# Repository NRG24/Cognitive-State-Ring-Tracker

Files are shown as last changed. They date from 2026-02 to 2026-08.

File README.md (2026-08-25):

# NERVA Ring

An open-source, sensor-packed smart ring designed to monitor cognitive health and autonomic nervous system metrics rather than traditional fitness tracking.

## Project Overview

The NERVA Ring shifts the focus of wearable technology away from step-counting and workouts toward real-time mental well-being. By embedding precise biosensors into a compact, flexible PCB form factor, the device continuously captures physiological indicators tied directly to stress, mental fatigue, and psychological arousal.

## Core Features

* **Cognitive Focus:** Tailored strictly for mental wellness monitoring rather than physical fitness or gym tracking.
* **Reviewed Hardware Design:** The v1 circuitry was modeled and validated in LT-Spice; the v2 netlist has been reviewed pin-by-pin against every device datasheet. No v2 board has been built or bench-validated yet.
* **Ultra-Compact Layout:** All hardware components optimized to fit onto a highly constrained, circular flex PCB architecture.
* **Wireless Telemetry:** Real-time, low-latency data streaming to mobile devices using Bluetooth Low Energy (BLE).
* **Intelligent Software Pipeline:** Dynamic in-app data filtering to remove motion artifacts and anomalies, powering a custom algorithm that delivers a "Cognitive Score" out of 100 alongside meaningful behavioral insights.

## Hardware Architecture

The current board is **NERVA Ring v2**, a complete part change from v1 — the MCU, both sensors, the op-amp, and the entire power path were replaced. Everything under `hardware/` and `firmware/` in this repo still describes the v1 board; see [Board Revisions](#board-revisions).

### Core components

| Role | Part | I²C address (7-bit) |
|---|---|---|
| MCU / BLE | u-blox ANNA-B402-00B (nRF52833) | — |
| PPG (HR / SpO2) | MAXM86161 | `0x62` (`0xC4`/`0xC5` 8-bit) |
| IMU + die temperature | ST LSM6DSV | `0x6B` — SA0 tied to 1V8 |
| PMIC / charger / fuel gauge | TI BQ25120A | `0x6A` (fixed) |
| GSR analog front end | TI OPA2333 (dual op-amp) | — |
| LED boost converter | TI TPS61240 (fixed 5 V) | — |

All three I²C devices share a single bus. The IMU sits at **`0x6B`, not the ST default `0x6A`**: SA0 was originally grounded, which collided with the BQ25120A's fixed `0x6A`, so it was moved to the 1V8 rail.

### Pin map

**ANNA-B402 module pin numbers are not nRF GPIO numbers.** The `Pxx.yy` column is what firmware addresses.

There is **no UART and no USB** on this board — SWD is the only wired interface, so logging has to go over RTT rather than a serial port.

Because XL1/XL2 are grounded, the low-frequency clock has to come from the internal RC oscillator. There is no crystal to select.

### Power architecture

* **BQ25120A** is charger, buck regulator, and fuel gauge in one part. It supplies the SYS rail feeding the ANNA module, both sensors, and the analog front end. There is no separate LDO and no 3.3 V rail — the 3V3 rail was deleted, nothing uses it, and the PMIC's load switch / LDO output stays off (`LSCTRL`, ball E3, is tied to GND).
* **SYS runs at 1.9 V, not the 1.8 V default.** The default's −2.5 % corner is 1.755 V, which is below the OPA2333's 1.800 V minimum supply and only 55 mV above the ANNA's 1.70 V brown-out threshold. 1.9 V clears both, and costs nothing in GSR accuracy because the measurement is ratiometric — the rail cancels out.
* **The TS (thermistor) pin, ball C3, is physically unroutable on this layout and floats.** With TS sensing active the charger faults and delivers no current, so `TS_EN` has to be cleared before the cell will charge at all.
* Disabling TS also removes JEITA over-temperature protection from a lithium cell worn against skin, so charge-temperature limiting has to be reimplemented against the LSM6DSV die temperature and applied through the PMIC's `CE` bit.
* **Battery percentage comes from the BQ25120A's VBMON.** The v1 board had no fuel gauge at all.
* **TPS61240** generates the fixed 5 V VLED rail for the PPG, gated by `BOOST_EN`. It exists because of the green LED: VF is 3.0–3.8 V, against 2.1–2.5 V for red and 1.6–1.9 V for IR.
* Battery capacity (mAh) is still an open decision — it sets the fast-charge current and any honest runtime estimate.

### GSR front end

* Excitation is gated by `GSR_PWR` (P0.11, high drive) so the analog section can be powered down between samples, saving roughly 37 µA.
* Output lands on **AIN1 (P0.03)**. The SAADC is configured **reference VDD/4, gain 1/4**, so full scale equals VDD and the reading is ratiometric against the same rail that drives the excitation — supply drift cancels. The internal 0.6 V reference breaks that property.
* **40 µs acquisition time** is required by the 100 kΩ source impedance of R6.
* The C10/R6 filter has a ~100 ms time constant; allow ~300 ms after powering the front end before the first valid sample.
* Sampling must stay at **≥10 Hz** — skin-conductance responses peak ~1.4 s after onset, which is ~14 samples across the rise at 10 Hz but only ~3 at 2 Hz.
* Nominal conversion, 12-bit (0–4095): `G[µS] ≈ code × 0.009692 − 10.989`. Derived from nominal resistor values, so it needs trimming against a known resistance.

### PPG front end

* The MAXM86161 is powered **entirely from the 5 V VLED rail**. It is single-supply with an internal LDO, so taking `BOOST_EN` low unpowers the part completely and resets every register — a full re-init is required on each duty cycle.
* **Its interrupt pin is deliberately left unconnected**; the FIFO has to be polled.
* The I²C bus runs at 1.8 V and the MAXM86161 needs VIH ≥ 1.4 V, so no level shifter is required despite the 5 V VLED.
* **LED current range is a power-path constraint.** At the 124 mA range the boost pulls ~186 mA from the cell; on a small ring LiPo (~3 Ω internal resistance) that is ~560 mV of droop and starts crowding the BQ25120A's UVLO. The 31 mA range draws ~45 mA, about 135 mV of droop.

### IMU

* LSM6DSV at `0x6B`, with INT1 wired to P0.16.
* It is **not** an LSM6DS3 — different `WHO_AM_I` and different ODR / full-scale register encodings, so v1 register values do not carry the same meaning.
* Embedded temperature sensor at `OUT_TEMP_L/H` (0x20/0x21), 256 LSB/°C with 0 LSB = 25 °C. This is the die temperature used for the software charge-temperature limiting described above.

```
NERVA_Ring/
├── app/                        # Flutter mobile app ("GSR Streamer")
│   ├── lib/
│   │   ├── main.dart           # App entry point
│   │   ├── ble_service.dart    # BLE communication layer
│   │   ├── cognitive_scorer.dart
│   │   ├── gsr_analyzer.dart
│   │   ├── models/             # Data models
│   │   ├── screens/            # UI screens
│   │   ├── services/           # Business logic services
│   │   └── widgets/            # Reusable UI components
│   └── pubspec.yaml
├── firmware/                   # Arduino firmware sketches
│   ├── gsr_heart_ble/          # Main firmware + docs
│   │   ├── gsr_heart_ble.ino   # BLE biometric streaming (XIAO prototype)
│   │   └── *.ino              # Variant sketches (power-optimized, all-features, etc.)
│   ├── simple_ble/             # Minimal BLE test
│   └── *.ino                  # Standalone test sketches
├── hardware/                   # Hardware design files (v1 board)
│   ├── NERVA RING-bom.csv      # JLCPCB bill of materials (v1)
│   ├── BOM.md                  # Formatted BOM reference (v1)
│   ├── gsr_wearable.kicad_sch  # KiCad schematic
│   ├── gsr_wearable.kicad_pro  # KiCad project
│   ├── Ring CAD.step           # 3D CAD model
│   ├── pcb/                    # PCB layout files
│   ├── SCHEMATIC_CHECKLIST.md  # Design review checklist
│   ├── GSR_CIRCUIT_INTEGRATION.md
│   ├── PCB_LAYOUT_STRATEGY.md
│   └── *.md                   # Additional design docs
├── docs/                       # Software architecture docs
│   ├── ACTIVITY_RECOGNITION.md
│   ├── STRESS_PATTERN_ANALYSIS.md
│   ├── HAPTIC_NOTIFICATIONS.md
│   └── *.md
└── scripts/                    # Build/utility scripts
```

## Bill of Materials (Summary)

Active components on the **v2** board:

| Component | Part | Qty |
|---|---|-----|
| MCU / BLE module | ANNA-B402-00B (u-blox, nRF52833) | 1 |
| PPG sensor | MAXM86161 | 1 |
| IMU | LSM6DSV | 1 |
| PMIC / charger / fuel gauge | BQ25120A | 1 |
| GSR op-amp | OPA2333 (dual) | 1 |
| LED boost converter | TPS61240 (fixed 5 V) | 1 |
| Battery | Curved ring-type LiPo — capacity TBD | 1 |

> The BOM files in this repo — [`hardware/BOM.md`](hardware/BOM.md) and the raw JLCPCB export [`hardware/NERVA RING-bom.csv`](hardware/NERVA%20RING-bom.csv) — are the **v1** build, including passives, costs and LCSC part numbers. A v2 BOM has not been generated.

## Sensors & Data Streams

| Metric | Sensor (v2) | BLE UUID (suffix) | Type |
|---|---|---|---|
| GSR (Skin Conductance) | OPA2333 front end → SAADC AIN1 | `...0002` | Int |
| Heart Rate | MAXM86161 PPG | `...0003` | Int |
| Temperature | LSM6DSV die temp | `...0004` | Float |
| HRV (RMSSD) | Derived from PPG | `...0005` | Float |
| SpO2 | MAXM86161 PPG | `...0006` | Int |
| Battery Level | BQ25120A VBMON | `...0007` | Int |

**BLE Service UUID:** `19B10000-E8F2-537E-4F6C-D104768A1214`

The v2 IMU also makes raw accelerometer and gyroscope streams available. UUIDs and payload types above describe the app currently in `app/`; the BLE characteristic set is firmware/app scope and is not covered by this hardware pass.

## Board Revisions

Every design file in `hardware/` and every sketch in `firmware/` describes the **v1** board. v2 replaced all of it:

| Role | v1 | v2 (current) |
|---|----|---|
| MCU / BLE | Raytac MDBT42V (nRF52832) | u-blox ANNA-B402-00B (nRF52833) |
| PPG | MAX30102 | MAXM86161 |
| IMU | LSM6DSR (LSM6DSRTR) | LSM6DSV |
| GSR op-amp | LM324PWR (quad) | OPA2333 (dual) |
| Power | TLV70018DDCR 1.8 V LDO | BQ25120A PMIC (charger + buck + fuel gauge) |
| LED supply | — | TPS61240 fixed 5 V boost |
| Temperature source | MAX30102 die temp | LSM6DSV die temp |
| Battery monitoring | none | BQ25120A VBMON |

Consequences worth knowing:

* The KiCad project, Gerbers, BOM, and all layout/schematic notes under `hardware/` are v1 and have not been regenerated.
* v1 firmware does not port to v2. Beyond the sensor changes, the Adafruit nRF52 Arduino core supports nRF52832/nRF52840 only, while the ANNA-B402 is an nRF52833.

**Within the v1 documents themselves**, several files still reference even earlier parts: `SCHEMATIC_CHECKLIST.md`, `PCB_LAYOUT_STRATEGY.md`, and `GSR_CIRCUIT_INTEGRATION.md` mention LSM6DS3, TLV9004 (UQFN-14), and a 3.3 V MCP1700T-3302E LDO, and the JLCPCB BOM CSV lists MDBT50Q-1MV2 in the MCU slot rather than the MDBT42V actually fitted. `hardware/BOM.md` tracks that list. The firmware docs in `firmware/gsr_heart_ble/` describe the XIAO nRF52840 prototyping setup, not a ring board of either revision.

## Getting Started

### Mobile App
```bash
cd app
flutter pub get
flutter run
```

### Firmware (Prototype with XIAO nRF52840)
1. Install Arduino IDE with Seeed nRF52 board support
2. Install libraries: `ArduinoBLE`, `OneWire`, `DallasTemperature`
3. Wire sensors per `firmware/gsr_heart_ble/SETUP_INSTRUCTIONS.md`
4. Upload `firmware/gsr_heart_ble/gsr_complete_all_features.ino`

### Hardware
The KiCad project, Gerbers, and BOM in `hardware/` are the **v1** board: a 2-layer flex design with components on both sides, 0402/0201 passives, assembled by JLCPCB. v2 design files are not in this repo — the v2 description above comes from its netlist and datasheet review.

Bringing up a v2 board: attach a debug probe to SWD (module pins 41/42) and power it from a partially charged cell. **A fresh board will not charge on its own** — the floating TS pin holds the BQ25120A off until firmware clears `TS_EN`.

---

https://github.com/user-attachments/assets/21d7508c-1ee5-49b8-9717-f8bbbc1bc319







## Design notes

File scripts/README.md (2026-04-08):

# scripts/ — nRF52832 Flash Tools (Raspberry Pi Debug Probe)

Scripts to erase and flash the Raytac MDBT42 (nRF52832) using a Raspberry Pi Debug Probe over SWD via OpenOCD.

---

## Hardware Wiring

| Raspberry Pi Debug Probe | nRF52832 (MDBT42) |
|---|---|
| SWDIO | SWDIO (P0.26) |
| SWCLK | SWDCLK (P0.27) |
| GND | GND |
| VTref (3.3V) | VDD (3.3V) |
| RESET (optional) | RESET |

> **Note:** Power the nRF52832 from an external supply or your PCB — do not rely on the probe to power the target unless it's a low-power test setup.

---

## Requirements

Install OpenOCD on the Raspberry Pi:

```bash
sudo apt update
sudo apt install openocd
```

Verify OpenOCD supports CMSIS-DAP (it should on modern Raspberry Pi OS):

```bash
openocd --version
```

---

## Files

| File | Purpose |
|---|---|
| `rpi_debug_probe.cfg`  | OpenOCD config — CMSIS-DAP/SWD, nRF52832 target |
| `flash.sh` | Flash a firmware `.hex` to the nRF52832 |
| `erase.sh` | Mass-erase the nRF52832 (clears all flash) |

---

## Usage

### 1. Copy scripts to Raspberry Pi

```bash
scp scripts/rpi_debug_probe.cfg scripts/flash.sh scripts/erase.sh pi@<PI_IP>:~/nrf52_tools/
ssh pi@<PI_IP>
chmod +x ~/nrf52_tools/flash.sh ~/nrf52_tools/erase.sh
```

### 2. Test connection (verify OpenOCD can see target)

```bash
openocd -f ~/nrf52_tools/rpi_debug_probe.cfg -c "init; reset halt; mdw 0x10000000; exit"
```

Expected output includes the chip ID — if you see `0x10000000: XXXXXXXX` the probe is connected.

### 3. Erase the chip (optional, do before flashing if chip is locked)

```bash
cd ~/nrf52_tools
./erase.sh
```

### 4. Flash firmware

```bash
cd ~/nrf52_tools
./flash.sh /path/to/firmware.hex
```

Example with Arduino-exported hex:

```bash
./flash.sh ~/firmware/gsr_heart_ble.ino.hex
```

---

## Building Firmware (two options)

### Option A — Arduino IDE (easiest)

1. Install **Arduino IDE 2.x**
2. Add nRF5 board support URL in preferences:
   ```
   https://sandeepmistry.github.io/arduino-nRF5/package_nRF5_index.json
   ```
3. Install board: **Nordic Semiconductor nRF5 Boards** → select **Nordic nRF52832**
4. Open `firmware/gsr_heart_ble/` sketch
5. Sketch → Export Compiled Binary → outputs a `.hex`
6. Copy `.hex` to RPi and flash with `./flash.sh`

### Option B — nRF5 SDK + ARM GCC

1. Download [nRF5 SDK 17.1.0](https://www.nordicsemi.com/Software-and-tools/Software/nRF5-SDK)
2. Install arm-none-eabi-gcc:
   ```bash
   sudo apt install gcc-arm-none-eabi
   ```
3. Build:
   ```bash
   cd <sdk>/examples/ble_peripheral/ble_app_uart/pca10040/s132/armgcc
   make
   ```
4. Flash the merged softdevice + app hex:
   ```bash
   ./flash.sh _build/nrf52832_xxaa.hex
   ```

---

## Softdevice Note

If using SoftDevice (BLE stack), you must flash it separately **once** before flashing your app:

```bash
# flash S132 softdevice first
./flash.sh /path/to/s132_nrf52_7.3.0_softdevice.hex

# then flash your app
./flash.sh /path/to/your_app.hex
```

Download S132 from: https://www.nordicsemi.com/Software-and-tools/Software/S132

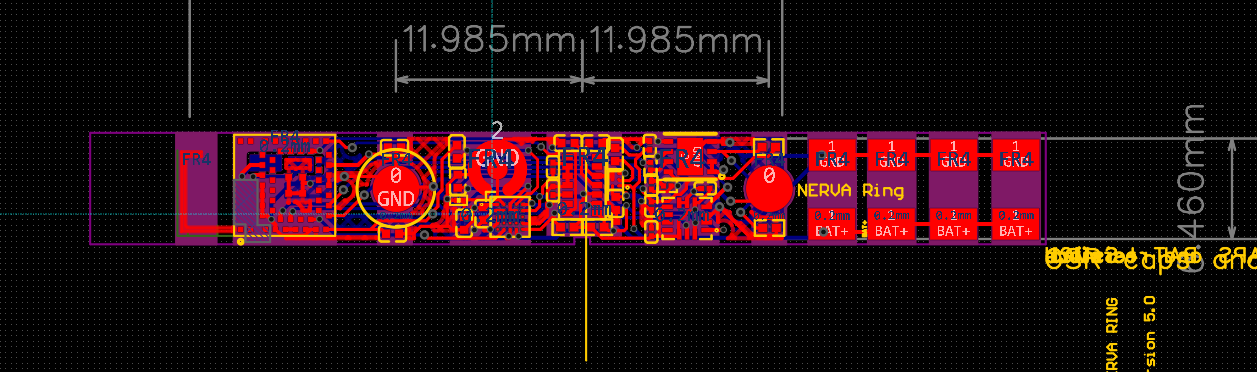
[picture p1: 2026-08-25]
hardware/pcb/PCB and Schematic/PCB_image.png

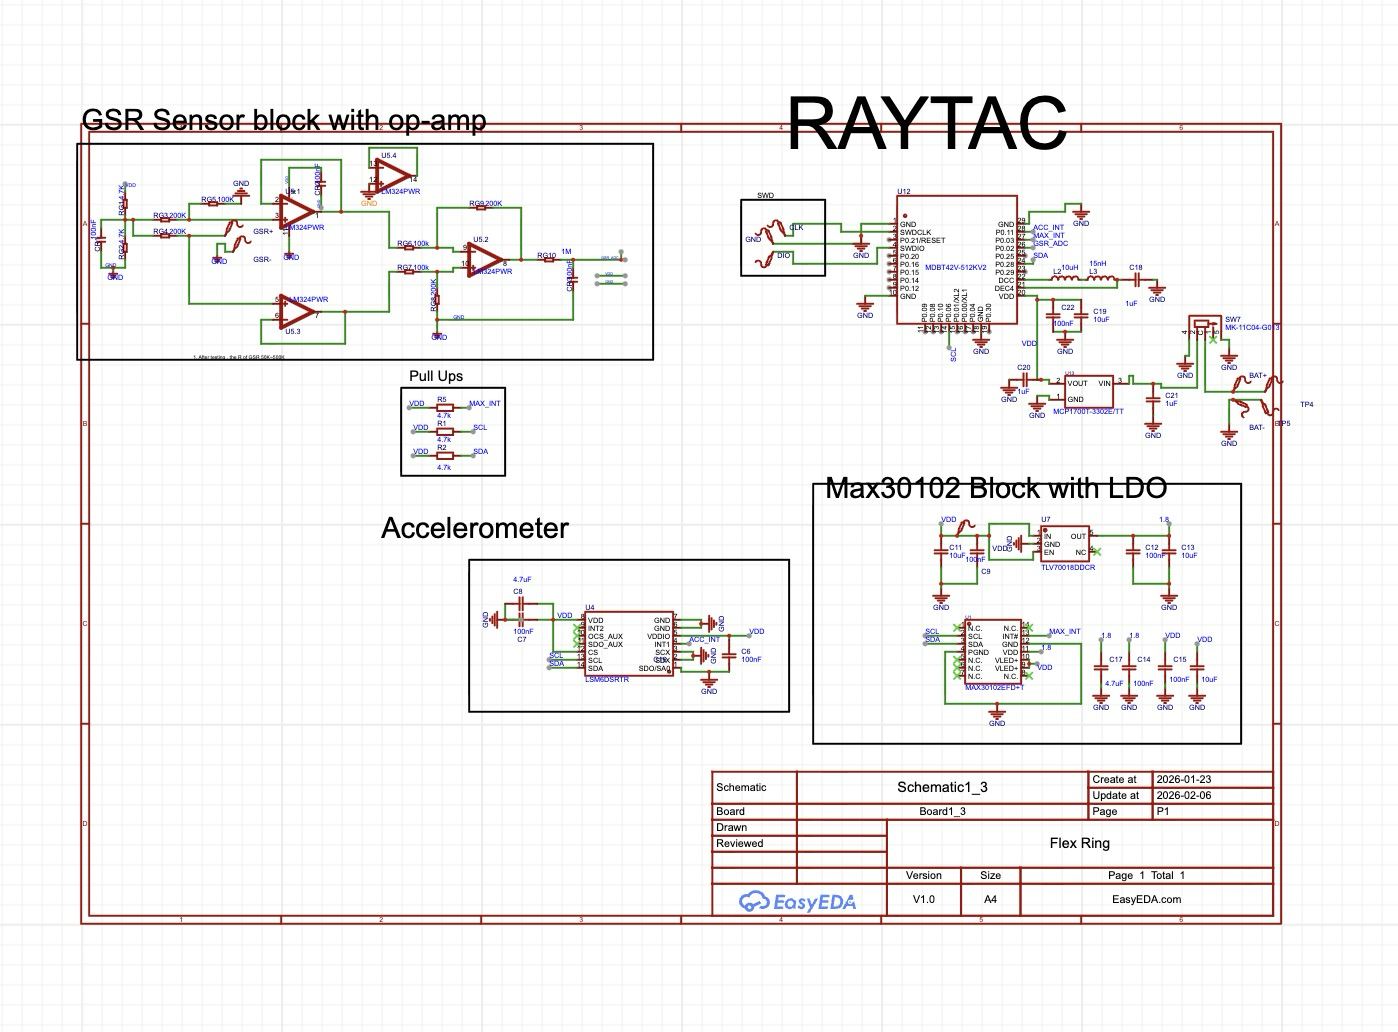
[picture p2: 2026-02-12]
hardware/pcb/PCB and Schematic/Schematic.png

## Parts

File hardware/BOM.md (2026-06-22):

# NERVA Ring - Bill of Materials

> **Source of truth:** [`NERVA RING-bom.csv`](NERVA%20RING-bom.csv) is the JLCPCB export. This document is a formatted reference.

## Order Summary

| Item | Description | Qty | Cost (USD) | Supplier |
|---|---|-----|---|---|
| Curved LiPo Battery | Ring-type rechargeable Li-Ion cell for wearable devices | 5 | $27.00 | Alibaba |
| Flex PCB + Assembly | 2-layer flex PCB with SMT assembly (all components except battery) | 2 | $160.60 | JLCPCB |
| Raytac MDBT42V-P | BLE MCU module (nRF52832), pre-order for PCB assembly | 2 | $11.06 | JLCPCB Pre-Order |
| | **Total** | | **$198.66** | |

## PCBA Parts List

Components placed by JLCPCB assembly service.

### Active Components (ICs)

| Ref | Part Number | Description | Package | Qty | Manufacturer | LCSC | Unit Price |
|-----|---|---|---|-----|---|---|---|
| U10 | MDBT42V-512KV2 | BLE MCU module (nRF52832) | SMD Module | 1 | Raytac | C5118826 | $1.02 |
| U1 | MAX30102EFD+T | PPG sensor (HR, SpO2, temp) | OESIP-14 (5.6x3.3mm) | 1 | Analog Devices / Maxim | C6454833 | $1.79 |
| U4 | LSM6DSRTR | 6-axis IMU (accel + gyro) | LGA-14 (3.0x2.5mm) | 1 | STMicroelectronics | C784817 | $0.41 |
| U5 | LM324PWR | Quad op-amp (GSR circuit) | TSSOP-14 (5.0x4.4mm) | 1 | Texas Instruments | C7942 | $0.03 |
| U7 | TLV70018DDCR | 1.8V LDO regulator | SOT-23-5 (3.0x1.7mm) | 1 | Texas Instruments | C79924 | $0.02 |

### Passive Components

#### Capacitors

| Ref | Value | Designators | Package | Qty | Notes |
|-----|---|---|---|-----|---|
| C6-C7, C9, C12, C14-C15, C_VDD1, C_VDDH1 | 100nF | Bypass / decoupling | 0402 | 8 | |
| C8, C17 | 4.7uF | Bulk decoupling | 0603 | 2 | |
| C11, C13, C16, C_VDD, C_VDDH | 10uF | Bulk decoupling | 0603 | 5 | |
| CR1, CR2, CR3 | 100nF | GSR circuit | 0402 | 3 | |

**Total capacitors: 18**

#### Resistors

| Ref | Value | Designators | Package | Qty | Notes |
|-----|---|---|---|-----|---|
| R1, R2, R5 | 4.7k | I2C pull-ups / general | 0402 | 3 | |
| R6 | 10K | General | 0402 | 1 | |
| RG1, RG2 | 4.7K | GSR circuit | 0402 | 2 | |
| RG3, RG4, RG8, RG9 | 200K | GSR feedback | 0402 | 4 | |
| RG5 | 100K | GSR circuit | 0402 | 1 | |
| RG6, RG7 | 100k | GSR circuit | 0402 | 2 | |
| RG10 | 1M | GSR output | 0402 | 1 | |

**Total resistors: 14**

#### Inductors

| Ref | Value | Designator | Package | Qty | Notes |
|-----|---|---|---|-----|---|
| L1 | 10uH | L1 | 0603 | 1 | DCDC circuit |

**Total inductors: 1**

### Connectors, Electrodes & Test Points

| Ref | Part | Designators | Qty | Notes |
|-----|---|---|-----|---|
| H4 | PZ254V-11-02P | H4 | 1 | 2-pin header (battery connector), LCSC C492401 |
| — | Custom pogo pins | GSR+, GSR- | 2 | GSR skin-contact electrodes |
| — | 2-pin magnetic pogo connector | CHRG | 1 | Magnetic charging connector (Alibaba) |
| BAT+, BAT- | Test-Point | BAT+, BAT- | 2 | Battery connection test points (2mm) |
| TP_VDD | Test-Point | TP_VDD | 1 | Power rail test point (0.5mm) |

## Component Count Summary

| Category | Count |
|---|---|
| ICs | 5 |
| Capacitors | 18 |
| Resistors | 14 |
| Inductors | 1 |
| Connectors | 3 |
| Test Points | 3 |
| **Total** | **44** |

## Discrepancies With Other Documentation

The JLCPCB BOM CSV lists MDBT50Q-1MV2 for the MCU slot, but the actual module used is the **MDBT42V** (nRF52832). The following docs have other stale references:

| Document | References | Actual Part on PCB |
|---|---|---|
| `SCHEMATIC_CHECKLIST.md` | LSM6DS3 | LSM6DSR (LSM6DSRTR) |
| `SCHEMATIC_CHECKLIST.md` | MCP1700T-3302E (3.3V LDO) | TLV70018DDCR (1.8V LDO) |
| `SCHEMATIC_CHECKLIST.md` | TLV9004 quad op-amp | LM324PWR |
| `PCB_LAYOUT_STRATEGY.md` | TLV9004IRUCR, LSM6DS3, MCP1700T-3302E | See above |
| `GSR_CIRCUIT_INTEGRATION.md` | TLV9004IRUCR (UQFN-14), 0201 passives | LM324PWR (TSSOP-14), 0402 passives |
| `GSR_CIRCUIT_INTEGRATION.md` | RG1 = 100kΩ | RG1 = 4.7K (per CSV BOM) |
| `GSR_CIRCUIT_INTEGRATION.md` | 100µF bulk cap (0603/0805) | No 100µF cap in BOM; largest is 10µF |

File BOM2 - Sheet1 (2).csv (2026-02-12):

Item | Quantity | Link | Price | Notes
Raytac MDBT42V | 2 | https://jlcpcb.com/partdetail/RAYTAC-MDBT50Q1MV2/C5118826 | 27.84 | Pre-order for PCBA
JLCPCB PCB | 5 | NA | 7.79
PCBA | 2 | NA | 231.47
Curved LiPo Battery | 5 | https://www.alibaba.com/product-detail/150728-22mAh_11000020635153.html | 30.9 | Already owned
 |  | Subtotal: | 267.1
 |  | Shipping: | 17.5 | This is Cheapest Shipping
 |  | Total: | 284.6
PCBA Parts list excluding Raytac MCU
No. | Quantity | Comment | Designator | Footprint | Value | Manufacturer Part | Manufacturer | Supplier Part | Supplier | JLCPCB Price
1 | 2 | Test-Point | BAT+,BAT- | Test-Point-2mm
2 | 8 | 100nF | C6,C7,C9,C12,C14,C15,C_VDD1,C_VDDH1 | C0402 | 100nF
3 | 2 | 4.7uF | C8,C17 | C0603 | 4.7uF
4 | 5 | 10uF | C11,C13,C16,C_VDD,C_VDDH | C0603 | 10uF
5 | 3 | 100nF | CR1,CR2,CR3 | C0402
6 | 1 | PZ254V-11-02P | H4 | HDR-TH_2P-P2.54-V-M |  | PZ254V-11-02P | XFCN(兴飞) | C492401 | LCSC | 0.0018
7 | 1 | 10uH | L1 | L0603 | 10uH
8 | 3 | 4.7k | R1,R2,R5 | R0402 | 4.7k
9 | 1 | 10K | R6 | R0402 | 10K
10 | 2 | 4.7K | RG1,RG2 | R0402
11 | 4 | 200K | RG3,RG4,RG8,RG9 | R0402
12 | 1 | 100K | RG5 | R0402
13 | 2 | 100k | RG6,RG7 | R0402
14 | 1 | 1M | RG10 | R0402
15 | 1 | Test-Point | TP_VDD | Test-Point-0.5mm
16 | 1 | MAX30102EFD+T | U1 | OESIP-14_L5.6-W3.3-P0.80-TL |  | MAX30102EFD+T | ADI(亚德诺)/MAXIM(美信) | C6454833 | LCSC | 1.7855
17 | 1 | LSM6DSRTR | U4 | LGA-14_L3.0-W2.5-P0.50-BR |  | LSM6DSRTR | ST(意法半导体) | C784817 | LCSC | 0.4076
18 | 1 | LM324PWR | U5 | TSSOP-14_L5.0-W4.4-P0.65-LS6.4-BL |  | LM324PWR | TI(德州仪器) | C7942 | LCSC | 0.0289
19 | 1 | TLV70018DDCR | U7 | SOT-23-5_L3.0-W1.7-P0.95-LS2.8-BR |  | TLV70018DDCR | TI(德州仪器) | C79924 | LCSC | 0.0249
20 | 1 | MDBT50Q-1MV2 | U10 | COMM-SMD_MDBT50Q-1MV2-1 |  | MDBT50Q-1MV2 | RAYTAC | C5118826 | LCSC | 1.0176

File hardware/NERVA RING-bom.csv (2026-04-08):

Name | Purpose | Quantity | Total Cost (USD) | Link | Distributor
Smart Cell for Small Wearable Devices High-Energy Compact Power Source Ring-Type Lithium-Ion Battery OEM ODM Rechargeable | Curved LiPo Battery to power the PCB | 5 | 27 | https://www.alibaba.com/product-detail/Smart-Cell-for-Small-Wearable-Devices_11000020635153.html | Alibaba (via Trusted Supplier I've used before)
Flex PCB + PCB Assembly | This is the flexible PCB with all of the needed components except for the battery- Assembly included. I got the cheapest shipping option available. | 2 | 160.6 |  | JLCPCB
Raytac MDBT42V - P | MCU- Preorder for PCB Assembly | 2 | 11.06 | https://jlcpcb.com/parts/componentSearch?searchTxt=mdbt42v-512kv2 | JLCPCB Pre-Order
 |  | Total: | 198.6
PCBA Parts list excluding Raytac MCU
No. | Quantity | Comment | Designator | Footprint | Value | Manufacturer Part | Manufacturer | Supplier Part | Supplier | JLCPCB Price
1 | 2 | Test-Point | BAT+,BAT- | Test-Point-2mm
2 | 8 | 100nF | C6,C7,C9,C12,C14,C15,C_VDD1,C_VDDH1 | C0402 | 100nF
3 | 2 | 4.7uF | C8,C17 | C0603 | 4.7uF
4 | 5 | 10uF | C11,C13,C16,C_VDD,C_VDDH | C0603 | 10uF
5 | 3 | 100nF | CR1,CR2,CR3 | C0402
6 | 1 | PZ254V-11-02P | H4 | HDR-TH_2P-P2.54-V-M |  | PZ254V-11-02P | XFCN(兴飞) | C492401 | LCSC | 0.0018
7 | 1 | 10uH | L1 | L0603 | 10uH
8 | 3 | 4.7k | R1,R2,R5 | R0402 | 4.7k
9 | 1 | 10K | R6 | R0402 | 10K
10 | 2 | 4.7K | RG1,RG2 | R0402
11 | 4 | 200K | RG3,RG4,RG8,RG9 | R0402
12 | 1 | 100K | RG5 | R0402
13 | 2 | 100k | RG6,RG7 | R0402
14 | 1 | 1M | RG10 | R0402
15 | 1 | Test-Point | TP_VDD | Test-Point-0.5mm
16 | 1 | MAX30102EFD+T | U1 | OESIP-14_L5.6-W3.3-P0.80-TL |  | MAX30102EFD+T | ADI(亚德诺)/MAXIM(美信) | C6454833 | LCSC | 1.7855
17 | 1 | LSM6DSRTR | U4 | LGA-14_L3.0-W2.5-P0.50-BR |  | LSM6DSRTR | ST(意法半导体) | C784817 | LCSC | 0.4076
18 | 1 | LM324PWR | U5 | TSSOP-14_L5.0-W4.4-P0.65-LS6.4-BL |  | LM324PWR | TI(德州仪器) | C7942 | LCSC | 0.0289
19 | 1 | TLV70018DDCR | U7 | SOT-23-5_L3.0-W1.7-P0.95-LS2.8-BR |  | TLV70018DDCR | TI(德州仪器) | C79924 | LCSC | 0.0249
20 | 1 | MDBT50Q-1MV2 | U10 | COMM-SMD_MDBT50Q-1MV2-1 |  | MDBT50Q-1MV2 | RAYTAC | C5118826 | LCSC | 1.0176

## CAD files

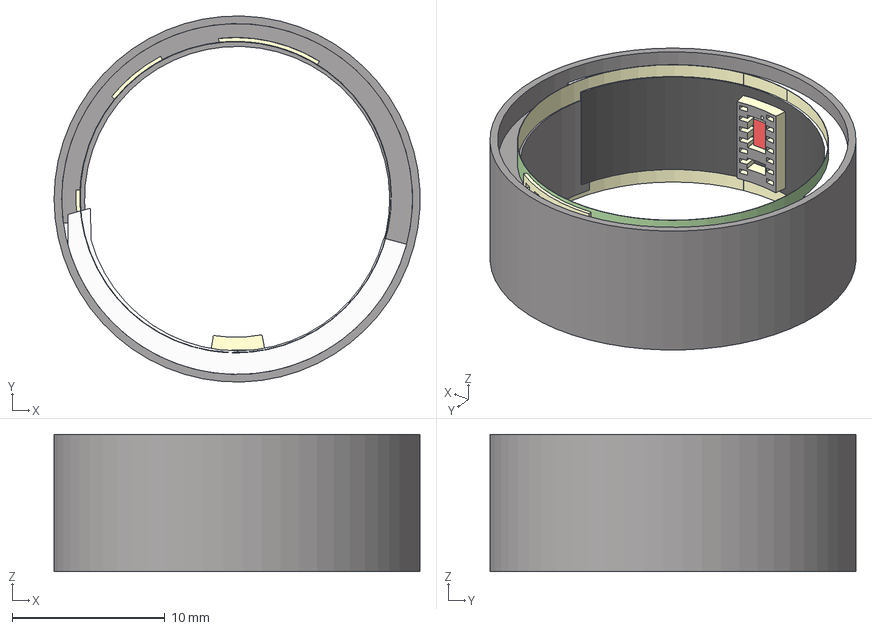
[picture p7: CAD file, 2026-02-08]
hardware/Ring CAD.step
24.0 x 24.0 x 9.00 mm

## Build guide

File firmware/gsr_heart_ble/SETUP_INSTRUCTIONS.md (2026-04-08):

# XIAO nRF52840 Complete Biometric System Setup

## 📋 Overview

This is the **complete Arduino sketch** that provides ALL features for the GSR Streamer Flutter app:
- ✅ GSR (Galvanic Skin Response) monitoring
- ✅ Heart Rate with pulse detection
- ✅ Heart Rate Variability (HRV/RMSSD)
- ✅ Finger Temperature (DS18B20)
- ✅ SpO2 Blood Oxygen (optional MAX30102)
- ✅ Battery level monitoring
- ✅ Real-time waveform data
- ✅ Power optimization with auto-sleep

---

# XIAO nRF52840 BLE GSR Sensor Setup Instructions

## Hardware Requirements

### Required Components:
1. **XIAO nRF52840 Board** - Main microcontroller
2. **GSR Sensor** - Galvanic Skin Response sensor
3. **Pulse Sensor** - Heart rate detection
4. **DS18B20 Temperature Sensor** - Waterproof version for finger temp
5. **4.7kΩ Resistor** - Pull-up for DS18B20
6. **Battery Components** (for battery monitoring):
   - 2x 10kΩ resistors (voltage divider)
   - 110-500mAh LiPo battery
7. **Breadboard and jumper wires**

### Optional Components:
- **MAX30102** - For accurate SpO2 blood oxygen measurement

---

## Complete Wiring Diagram

```
XIAO nRF52840 Pin Connections:
╔════════════════════════════════════════════════════════════╗
║ SENSOR CONNECTIONS                                         ║
╠════════════════════════════════════════════════════════════╣
║ A0 ──────► GSR Sensor (Signal)                             ║
║ A1 ──────► Pulse Sensor (Signal)                           ║
║ D6 ──────► DS18B20 (Data) + 4.7kΩ pull-up to 3.3V         ║
║ A5 ──────► Battery Voltage (via voltage divider)           ║
║ SDA ─────► MAX30102 SDA (optional)                         ║
║ SCL ─────► MAX30102 SCL (optional)                         ║
║ 3V3 ─────► All sensors VCC                                 ║
║ GND ─────► All sensors GND                                 ║
║ LED ─────► Built-in (connection indicator)                 ║
╚════════════════════════════════════════════════════════════╝
```

### Battery Voltage Monitor Circuit

```
Battery Voltage Divider (for battery % monitoring):

    Battery+ (4.2V max)
        │
       ┌┴┐
       │R│ 10kΩ
       └┬┘
        ├────────► A5 (XIAO) [measures ~2.1V max]
        │
       ┌┴┐
       │R│ 10kΩ
       └┬┘
        │
       GND

This divides battery voltage by 2, so XIAO can safely measure it.
```

### Detailed Connections

#### GSR Sensor
- **VCC** → XIAO 3.3V
- **GND** → XIAO GND
- **Signal** → XIAO A0

#### Pulse Sensor
- **Red Wire (VCC)** → XIAO 3.3V
- **Black Wire (GND)** → XIAO GND
- **Purple Wire (Signal)** → XIAO A1

#### DS18B20 Temperature Sensor
- **Red Wire (VCC)** → XIAO 3.3V
- **Black Wire (GND)** → XIAO GND
- **Yellow Wire (Data)** → XIAO D6
- **4.7kΩ Resistor** → Between Data (D6) and VCC (3.3V)

```
Temperature Sensor Pull-up Resistor:
       3.3V
        │
       ┌┴┐
       │R│ 4.7kΩ
       └┬┘
        │
        ├────────► D6 (XIAO)
        │
      ──┴──  DS18B20 Data Pin
```

## Required Arduino Libraries

Install these libraries via Arduino IDE Library Manager:

1. **ArduinoBLE** (version 1.3.6 or later)
   - For: BLE communication
   - Install: `Sketch > Include Library > Manage Libraries > Search "ArduinoBLE"`

2. **OneWire** (version 2.3.7 or later)
   - For: DS18B20 communication protocol
   - Install: `Sketch > Include Library > Manage Libraries > Search "OneWire"`

3. **DallasTemperature** (version 3.9.0 or later)
   - For: DS18B20 temperature sensor interface
   - Install: `Sketch > Include Library > Manage Libraries > Search "DallasTemperature"`

## Board Setup in Arduino IDE

1. **Install XIAO nRF52840 Board Support**
   - Open Arduino IDE
   - Go to `File > Preferences`
   - Add to "Additional Boards Manager URLs":
     ```
     https://files.seeedstudio.com/arduino/package_seeeduino_boards_index.json
     ```
   - Go to `Tools > Board > Boards Manager`
   - Search for "Seeed nRF52 Boards"
   - Install "Seeed nRF52 Boards" by Seeed Studio

2. **Select Board**
   - `Tools > Board > Seeed nRF52 Boards > Seeed XIAO BLE - nRF52840`

3. **Select Port**
   - Connect XIAO via USB-C
   - `Tools > Port > [Select your XIAO port]`

## Upload Instructions

1. **Open the sketch**
   - Open `gsr_heart_temp_complete.ino` in Arduino IDE

2. **Verify Hardware is Connected**
   - Connect all sensors as per wiring diagram
   - Ensure 4.7kΩ pull-up resistor is in place for DS18B20

3. **Upload**
   - Click "Upload" button (→) in Arduino IDE
   - Wait for "Done uploading" message

4. **Monitor Serial Output**
   - Open Serial Monitor (`Tools > Serial Monitor`)
   - Set baud rate to **115200**
   - You should see:
     ```
     ═══════════════════════════════════════════════
     GSR Streamer - Complete Biometric System v2.0
     ═══════════════════════════════════════════════
     Initializing DS18B20 temperature sensor... Found 1 device(s)
     Initializing BLE... OK
     BLE advertising started as 'GSR_HEART'
     Waiting for connection...
     ═══════════════════════════════════════════════
     ```

---

## 📊 What Data Does This Send?

The complete sketch sends **6 data streams** to your Flutter app:

### 1. **GSR (Galvanic Skin Response)**
- **UUID:** 19B10002-E8F2-537E-4F6C-D104768A1214
- **Type:** Integer (0-1023)
- **Update Rate:** 10 times/second
- **What it measures:** Skin conductance (stress, arousal, emotion)
- **Used for:** Stress detection, trigger identification, baseline tracking

### 2. **Heart Rate**
- **UUID:** 19B10003-E8F2-537E-4F6C-D104768A1214
- **Type:** Integer (BPM)
- **Range:** 30-200 BPM
- **Update Rate:** Real-time (on each heartbeat)
- **What it measures:** Beats per minute with 5-beat smoothing
- **Used for:** Activity recognition, stress analysis, waveform display

### 3. **Temperature**
- **UUID:** 19B10004-E8F2-537E-4F6C-D104768A1214
- **Type:** Float (°Celsius)
- **Range:** 20-45°C typical
- **Update Rate:** Every 2 seconds
- **What it measures:** Finger temperature via DS18B20
- **Used for:** Stress patterns, health monitoring, waveform display

### 4. **HRV (Heart Rate Variability)**
- **UUID:** 19B10005-E8F2-537E-4F6C-D104768A1214
- **Type:** Float (milliseconds)
- **Calculation:** RMSSD (Root Mean Square of Successive Differences)
- **Update Rate:** After each heartbeat (calculated from last 10 RR intervals)
- **What it measures:** Variation between heartbeats
- **Used for:** Stress level, recovery status, autonomic balance
- **Note:** Higher HRV = better (more relaxed/recovered)

### 5. **SpO2 (Blood Oxygen)**
- **UUID:** 19B10006-E8F2-537E-4F6C-D104768A1214
- **Type:** Integer (%)
- **Range:** 70-100%
- **Update Rate:** Continuous (if MAX30102 connected)
- **What it measures:** Blood oxygen saturation
- **Used for:** Health monitoring, activity recognition
- **Note:** Currently simulated (98%) - requires MAX30102 for real data

### 6. **Battery Level**
- **UUID:** 19B10007-E8F2-537E-4F6C-D104768A1214
- **Type:** Integer (%)
- **Range:** 0-100%
- **Update Rate:** Every 10 seconds
- **What it measures:** LiPo battery charge percentage
- **Used for:** Low battery warnings, power management

---

## ⚡ Power Management Features

The sketch includes **smart power optimization**:

### When Connected (Active Mode):
- All sensors active
- Data sent every 100ms
- LED on solid
- Power draw: ~15-20mA

### When Disconnected (Idle Mode):
- Light sleep after 0 seconds
- Still advertising for connections
- Slower polling
- Power draw: ~5-10mA

### Deep Sleep (After 60 seconds idle):
- Ultra-low power mode
- Only BLE advertising active
- Slow "heartbeat" LED (2 second blink)
- Power draw: ~0.5-2mA
- **Battery life:** Days to weeks!

---

## LED Status Indicators

| Pattern | Meaning |
|---|---|
| **3 Fast Blinks** (startup) | System ready, BLE advertising |
| **Solid ON** | Connected to app, streaming data |
| **Quick pulse with heartbeat** | Heart beat detected |
| **Slow blink (2s)** | Deep sleep mode, waiting for connection |
| **Rapid flashing** | Error - check Serial Monitor |

---

## 🔧 Calibration & Tuning

### Pulse Sensor Threshold
If heart rate is not detecting properly:

```cpp
const int PULSE_THRESHOLD = 550;  // Line 67 - adjust this!
```

- **Too low (< 500):** False beats, erratic readings
- **Too high (> 650):** Misses beats
- **Sweet spot:** Usually 520-580 depending on your sensor

**How to calibrate:**
1. Open Serial Monitor
2. Watch raw pulse values
3. Set threshold to ~70% of peak value

### Battery Voltage Calibration

## Troubleshooting

### Temperature Sensor Not Detected
**Symptoms**: "Temperature sensors found: 0"

**Solutions**:
1. Check 4.7kΩ pull-up resistor is connected between Data (D6) and 3.3V
2. Verify DS18B20 wiring (Red=VCC, Black=GND, Yellow=Data)
3. Try a different DS18B20 sensor (they can fail)
4. Measure resistance between Data and VCC pins (should be ~4.7kΩ)

### No Heart Rate Detection
**Symptoms**: BPM stays at 0

**Solutions**:
1. Ensure Pulse Sensor is firmly pressed against fingertip
2. Clean the sensor surface
3. Adjust `PULSE_THRESHOLD` in code (line 21) - try values 500-600
4. Check Serial Monitor for "♥ Beat detected!" messages
5. Ensure good skin contact with the sensor

### GSR Values Stuck or Not Changing
**Symptoms**: GSR reads constant value

**Solutions**:
1. Attach GSR electrodes to clean, dry skin (fingers work best)
2. Ensure electrodes have good contact
3. Wait 30-60 seconds for sensor to stabilize
4. Check that GSR sensor is powered (3.3V)

### BLE Connection Issues
**Symptoms**: Flutter app can't find device

**Solutions**:
1. Verify device name is "GSR_HEART" in Serial Monitor
2. Check UUIDs match between Arduino and Flutter app
3. Reset XIAO (press reset button)
4. Move phone/computer closer to XIAO
5. Turn Bluetooth off/on on phone
6. Close other BLE apps that might interfere

### Temperature Reading Errors
**Symptoms**: "Warning: Temperature sensor read error"

**Solutions**:
1. Check DS18B20 is genuine (many clones exist)
2. Verify pull-up resistor value (4.7kΩ)
3. Shorten wires if connection is long (>1 meter)
4. Try a different digital pin
5. Power cycle the XIAO

## Sensor Calibration

### Pulse Sensor Auto-Calibration
The sketch automatically calibrates the pulse threshold every 5 seconds based on signal range. For manual tuning:
- Open Serial Monitor
- Observe signal min/max values
- Set `PULSE_THRESHOLD` to midpoint between min and max

### GSR Baseline
GSR values vary by person and conditions. Typical ranges:
- **Dry skin**: 200-400
- **Normal**: 400-600
- **Sweaty/stressed**: 600-800+

### Temperature Reference
- **Normal finger temp**: 30-35°C (86-95°F)
- **Cold hands**: 25-30°C (77-86°F)
- **Warm/active**: 35-37°C (95-99°F)

## Data Stream Format

### BLE Characteristics

| Characteristic | UUID | Data Type | Range | Update Rate |
|---|---|---|---|---|
| GSR | 19B10002 | Int32 (LE) | 0-1023 | 20 Hz |
| Heart Rate | 19B10003 | Int32 (LE) | 30-200 BPM | 20 Hz |
| Temperature | 19B10004 | Float32 (LE) | 20-45°C | 0.5 Hz |

### Serial Debug Output Format
```
GSR: 512 | BPM: 72 | Temp: 32.5°C
♥ Beat detected! BPM: 75
```

## Power Consumption

- **Scanning**: ~15 mA
- **Connected & Streaming**: ~20 mA
- **Battery Life** (500 mAh LiPo): ~20-25 hours continuous use

## Safety Notes

⚠️ **Important Safety Information**:
- This is a DIY educational device, **NOT** medical equipment
- Do not use for medical diagnosis or treatment
- Ensure all connections are insulated to prevent shorts
- Use only 3.3V power supply (XIAO's voltage)
- Do not submerge electronics (only DS18B20 probe if waterproof)

## Next Steps

Once hardware is set up and sketch is uploaded:

1. **Verify Serial Output**: Confirm all sensors are detected
2. **Test Flutter App**: Run `flutter run -d iPhone` or `flutter run -d macos`
3. **Connect**: Tap "Connect to Device" in app
4. **Monitor Data**: Watch real-time waveforms update
5. **Calibrate**: Allow 2-3 minutes for sensors to stabilize

## Support

For issues or questions:
- Check Serial Monitor output for error messages
- Verify all wiring matches diagram
- Ensure libraries are up to date
- Try each sensor individually to isolate problems

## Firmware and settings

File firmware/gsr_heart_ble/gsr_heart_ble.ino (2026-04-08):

#include <Wire.h>
#include "MAX30105.h"
#include "heartRate.h"
#include <ArduinoBLE.h>  // BLE activated!

MAX30105 particleSensor;

// BLE Service and Characteristics - exact Flutter app UUIDs
BLEService gsrService("19B10000-E8F2-537E-4F6C-D104768A1214");
BLEIntCharacteristic gsrCharacteristic("19B10002-E8F2-537E-4F6C-D104768A1214", BLERead | BLENotify);
BLEIntCharacteristic heartCharacteristic("19B10003-E8F2-537E-4F6C-D104768A1214", BLERead | BLENotify);
BLEFloatCharacteristic tempCharacteristic("19B10004-E8F2-537E-4F6C-D104768A1214", BLERead | BLENotify);

// BLE variables - ready to activate
bool deviceConnected = false;

// Temperature variables
float temperature = 0.0;
unsigned long lastTempRead = 0;
const unsigned long TEMP_READ_INTERVAL = 2000; // Read temperature every 2 seconds

const byte RATE_SIZE = 20;  //Increased for much smoother averaging
byte rates[RATE_SIZE];     //Array of heart rates
byte rateSpot = 0;
long lastBeat = 0;  //Time at which the last beat occurred

float beatsPerMinute;
int beatAvg;
float smoothedBPM = 0.0;  //Additional smoothing layer

// GSR Variables - simple
const int GSR_PIN = A0;
float gsrValue = 0.0;
float gsrBaseline = 0.0;
float gsrVariability = 0.0;
const int GSR_SAMPLES = 10;
float gsrReadings[GSR_SAMPLES] = {0};
int gsrIndex = 0;

// HRV Variables - minimal and careful
const int HRV_BUFFER_SIZE = 10;
unsigned long rrIntervals[HRV_BUFFER_SIZE];
int rrIndex = 0;
unsigned long lastRRTime = 0;
float hrv = 0.0;

// SpO2 Variables - simple and careful
float spo2 = 0.0;
float redACValue = 0, irACValue = 0;
float redDCValue = 0, irDCValue = 0;
int spo2SampleCount = 0;

void setup() {
  Serial.begin(9600);
  Serial.println("Initializing...");

  // Initialize sensor
  if (!particleSensor.begin(Wire, I2C_SPEED_FAST)) {
    Serial.println("MAX30102 was not found. Please check wiring/power. ");
    while (1)
      ;
  }
  Serial.println("Place your index finger on the sensor with steady pressure.");

  particleSensor.setup();                     //Configure sensor with default settings
  particleSensor.setPulseAmplitudeRed(0x0A);  //Turn Red LED to low to indicate sensor is running
  particleSensor.setPulseAmplitudeGreen(0);   //Turn off Green LED
  
  // Enable temperature reading
  particleSensor.enableDIETEMPRDY();  //Enable the temp ready interrupt
  
  // Initialize BLE (placeholder for now)
  initializeBLE();
}

void loop() {
  long irValue = particleSensor.getIR();
  uint32_t redValue = particleSensor.getRed(); // Get red value for SpO2

  if (checkForBeat(irValue) == true) {
    //We sensed a beat!
    long delta = millis() - lastBeat;
    lastBeat = millis();

    beatsPerMinute = 60 / (delta / 1000.0);

    if (beatsPerMinute < 255 && beatsPerMinute > 20) {
      rates[rateSpot++] = (byte)beatsPerMinute;  //Store this reading in the array
      rateSpot %= RATE_SIZE;                     //Wrap variable

      //Take average of readings
      beatAvg = 0;
      for (byte x = 0; x < RATE_SIZE; x++)
        beatAvg += rates[x];
      beatAvg /= RATE_SIZE;
      
      // Additional exponential smoothing for very stable BPM
      if (smoothedBPM == 0.0) {
        smoothedBPM = beatAvg;  // Initialize on first reading
      } else {
        smoothedBPM = (smoothedBPM * 0.85) + (beatAvg * 0.15);  // Heavy smoothing
      }
      
      // HRV calculation - only when we have valid beats
      if (lastRRTime > 0) {
        unsigned long rrInterval = millis() - lastRRTime;
        if (rrInterval > 400 && rrInterval < 1500) { // Tighter range for more realistic RR intervals (40-150 BPM)
          rrIntervals[rrIndex] = rrInterval;
          rrIndex = (rrIndex + 1) % HRV_BUFFER_SIZE;
          calculateHRV();
        }
      }
      lastRRTime = millis();
    }
  }

  // SpO2 calculation - simple and non-interfering
  if (irValue > 50000 && redValue > 1000) {
    calculateSpO2(irValue, redValue);
  }

  // Simple GSR reading with baseline calculation
  updateGSR();
  
  // Read temperature periodically (not every loop - it's slower)
  if (millis() - lastTempRead >= TEMP_READ_INTERVAL) {
    temperature = particleSensor.readTemperature();
    lastTempRead = millis();
  }

  Serial.print("IR=");
  Serial.print(irValue);
  Serial.print(", Final BPM=");
  Serial.print(beatsPerMinute);
  Serial.print(", Avg BPM=");
  Serial.print(beatAvg);
  Serial.print(", Smooth BPM=");
  Serial.print(smoothedBPM, 1);
  Serial.print(", Signal Quality=");
  Serial.print(irValue > 50000 ? "GOOD" : "POOR");
  Serial.print(", GSR=");
  Serial.print(gsrValue);
  Serial.print(", HRV=");
  Serial.print(hrv);
  Serial.print(", SpO2=");
  Serial.print(spo2);
  Serial.print(", Temp=");
  Serial.print(temperature, 1);
  Serial.print("°C");

  if (irValue < 50000)
    Serial.print(" No finger?");

  if (deviceConnected) {
    Serial.print(" [BLE Connected]");
  } else {
    Serial.print(" [BLE Advertising]");
  }

  Serial.println();
  
  // Send BLE data in Flutter app format
  sendBLEData();
}

void calculateHRV() {
  if (rrIndex < 3) return; // Need at least 3 intervals
  
  float sumSquaredDifferences = 0;
  int validPairs = 0;
  
  // Calculate RMSSD (simple HRV measure)
  for (int i = 1; i < HRV_BUFFER_SIZE; i++) {
    if (rrIntervals[i] > 0 && rrIntervals[i-1] > 0) {
      long diff = rrIntervals[i] - rrIntervals[i-1];
      sumSquaredDifferences += (diff * diff);
      validPairs++;
    }
  }
  
  if (validPairs > 1) {
    float rmssd = sqrt(sumSquaredDifferences / validPairs);
    // Scale down the HRV to realistic range and apply limits
    rmssd = rmssd * 0.3; // Scale down significantly
    rmssd = constrain(rmssd, 15, 80); // Realistic HRV range
    hrv = (hrv * 0.9) + (rmssd * 0.1); // Heavy smoothing
  }
}

void calculateSpO2(long irValue, uint32_t redValue) {
  // Initialize DC values on first run
  if (spo2SampleCount == 0) {
    redDCValue = redValue;
    irDCValue = irValue;
    spo2 = 98.0; // Start with normal value
  }
  
  // Calculate AC components (variation from baseline)
  redACValue = abs(redValue - redDCValue);
  irACValue = abs(irValue - irDCValue);
  
  // Update DC baseline slowly
  redDCValue = (redDCValue * 0.95) + (redValue * 0.05);
  irDCValue = (irDCValue * 0.95) + (irValue * 0.05);
  
  spo2SampleCount++;
  
  // Calculate SpO2 after enough samples
  if (spo2SampleCount > 100 && irACValue > 0 && redACValue > 0) {
    float ratio = (redACValue / redDCValue) / (irACValue / irDCValue);
    
    // Simple SpO2 calculation using standard curve
    float calculatedSpO2;
    if (ratio < 0.5) {
      calculatedSpO2 = 100;
    } else if (ratio < 1.0) {
      calculatedSpO2 = 100 - 5 * ratio;
    } else if (ratio < 2.0) {
      calculatedSpO2 = 100 - 25 * ratio;
    } else {
      calculatedSpO2 = 85;
    }
    
    // Clamp to reasonable range
    calculatedSpO2 = constrain(calculatedSpO2, 85, 100);
    
    // Apply smoothing
    spo2 = (spo2 * 0.9) + (calculatedSpO2 * 0.1);
  }
}

void updateGSR() {
  float rawGSR = analogRead(GSR_PIN);
  gsrValue = rawGSR;

  // Update baseline using moving average
  gsrReadings[gsrIndex] = gsrValue;
  gsrIndex = (gsrIndex + 1) % GSR_SAMPLES;
  
  float sum = 0;
  for (int i = 0; i < GSR_SAMPLES; i++) {
    sum += gsrReadings[i];
  }
  gsrBaseline = sum / GSR_SAMPLES;
  
  // Calculate variability
  gsrVariability = gsrBaseline > 0 ? abs(gsrValue - gsrBaseline) / gsrBaseline : 0;
}

void sendBLEData() {
  // Check for BLE connection changes
  BLEDevice central = BLE.central();
  
  if (central) {
    if (!deviceConnected) {
      deviceConnected = true;
      Serial.println("BLE device connected!");
    }
    
    // Send data as binary values (Int and Float, NOT strings)
    gsrCharacteristic.writeValue((int)gsrValue);  // Send GSR as integer
    heartCharacteristic.writeValue((int)smoothedBPM);  // Send heart rate as integer
    tempCharacteristic.writeValue(temperature);  // Send temperature as float
    
    // Debug output
    Serial.print("BLE_GSR: ");
    Serial.print((int)gsrValue);
    Serial.print(" | BLE_HEART: ");
    Serial.print((int)smoothedBPM);
    Serial.print(" BPM | BLE_TEMP: ");
    Serial.print(temperature, 2);
    Serial.println("°C");
    
  } else {
    if (deviceConnected) {
      deviceConnected = false;
      Serial.println("BLE device disconnected!");
    }
  }
}

void initializeBLE() {
  // Initialize BLE
  if (!BLE.begin()) {
    Serial.println("Starting BLE failed!");
    while (1);
  }

  // Set BLE device name and service
  BLE.setLocalName("GSR_HEART");
  BLE.setAdvertisedService(gsrService);

  // Add characteristics to service
  gsrService.addCharacteristic(gsrCharacteristic);
  gsrService.addCharacteristic(heartCharacteristic);
  gsrService.addCharacteristic(tempCharacteristic);

  // Add service
  BLE.addService(gsrService);

  // Set initial values (as binary, not strings)
  gsrCharacteristic.writeValue(0);
  heartCharacteristic.writeValue(0);
  tempCharacteristic.writeValue(0.0);

  // Start advertising
  BLE.advertise();
  Serial.println("BLE device active, waiting for connections...");
}

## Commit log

2025-12-12 Easy access to PCB
2025-12-12 Update README with PCB estimate and BOM details
    Added PCB cost estimate and BOM link to README.
2025-12-12 Update README with project details and PCB estimate
    Added information about project resources and PCB cost estimate.
2025-12-13 Clean up README by removing outdated information
    Removed update section and Bill of Materials link from README.
2026-01-06 CAD FILE
    [Cognitive_Tracker.stl]
2026-01-25 Revise README to enhance project description
    Updated the README to include an accelerometer and emphasize the focus on cognitive health. Added details about testing circuitry in LT-Spice.
2026-01-26 Update README with flex PCB details
    Added additional context regarding the flex PCB and its components.
2026-04-08 Repo restructure: hardware/pcb, arduino/xiao, app/other; moved sketches and PCB files
2026-04-08 chore: reorganize repo into 5 folders (docs, firmware, hardware, scripts, app)
    Agent-Logs-Url: https://github.com/NRG24/Cognitive-State-Ring-Tracker/sessions/de9945f7-d82a-4161-8b5d-edef97d8b796
    [NERVA RING-bom.csv, Ring CAD.step, rpi_debug_probe.cfg]
2026-04-08 Fix nRF52 flash scripts, update Info.plist BT permissions, add scripts/README
    [rpi_debug_probe.cfg]
2026-06-22 Fix README hardware references and populate BOM from JLCPCB data
    The README listed outdated components (nRF52832, generic accelerometer)
    that no longer match the actual PCB. Updated all hardware references to
    match the JLCPCB BOM CSV (MDBT50Q-1MV2, LSM6DSR, LM324PWR, TLV70018DDCR).
    Added project structure, BOM summary table, sensor/BLE data stream
    reference, getting-started section, and a table documenting known
    inconsistencies in older design docs.
    Populated the previously empty hardware/BOM.md with a formatted
    breakdown of all 42 PCBA components from the CSV, including IC details,
    passive values/designators, and a discrepancy table cross-referencing
    stale docs.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
2026-06-22 Correct MCU to MDBT42V, add pogo electrodes and magnetic charger
    MCU is MDBT42V (nRF52832), not MDBT50Q as the JLCPCB CSV had listed.
    Added custom pogo-pin GSR electrodes and 2-pin magnetic pogo charger
    connector to the hardware architecture and BOM.
    Claude-Session: https://claude.ai/code/session_01JgJD4875FKb2nHt5BBeGq7
2026-08-15 Update README hardware sections for the v2 board
    Replaces the v1 hardware description with the v2 design: ANNA-B402-00B
    (nRF52833), MAXM86161 PPG, LSM6DSV IMU, BQ25120A PMIC, OPA2333 front end
    and TPS61240 5 V LED boost.
    Adds the module pin map (ANNA module pins vs nRF ports), I2C addressing
    including the IMU's move to 0x6B to clear the PMIC's fixed 0x6A, the
    power architecture (1.9 V SYS rail, floating TS pin, VBMON fuel gauge),
    per-subsystem notes for the GSR, PPG and IMU front ends, and bring-up
    notes covering the SWD-only debug path and the no-firmware-no-charge
    behaviour.
    Reframes the stale-docs section as Board Revisions: everything under
    hardware/ and firmware/ is v1, and the v1 BOM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
